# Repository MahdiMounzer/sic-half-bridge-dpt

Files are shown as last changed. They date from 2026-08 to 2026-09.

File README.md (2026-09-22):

# SiC Half-Bridge Inverter Leg + Double Pulse TEST (DPT)

A documented design-to-characterization project: a SiC half-bridge inverter leg with low-inductance 4-layer PCB, progressive bring-up, and DPT characterization (Eon/Eoff, dv/dt, overshoot, conduction losses).

## Motivation
Portfolio piece targeting EV / power electronics roles. Every design decision, measurement, and failure is documented as it happens.

## Status
**Stage0 - Design study** (operation point, device selection, gate loop, DC link, inductive load, LTspice simulation).

## Roadmap
1. Design study (Stage 0)
2. Schematic capture (KiCad)
3. 4-layer PCB - low loop inductance, kelvin source, separated power/signal
4. Progressive bring-up (20V -> 50V -> 100V -> 200V)
5. DPT characterization

## Structure
- 'design/' - design study and specifications
- 'schematic/' - KiCad schematic
- 'simulation/' - LTspice files
- 'measurements/' - DPT data, scope captures
- 'calculations/' - Math behind my choices
- 'logbook/' - chronological notes, failures learnings

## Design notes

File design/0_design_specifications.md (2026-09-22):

# Design Specifications - Stage 0

## 1. Operating point
- DC link voltage (nominal / max test): 200 V (architecture 800 V-ready)
- Target switching current: 10 A
- Switching frequency (if applicable): 50 kHz - 100 kHz
- Test type: Double Pulse Test (only the low-side device is actively switched; the high-side body diode freewheels the inductor current)

## 2. SiC MOSFET selection
Requirement: TO-247-4 with Kelvin source pin (mandatory).
Candidates:
- Wolfspeed C3M0045065K
- Infineon IMZA65R048M1H
- onsemi NTH4LN032N065M3S

Decision: **onsemi NTH4LN032N065M3S**
- Key ratings: 650 V, 32 mΩ, TO-247-4L (thin leads, Kelvin source), recommended gate drive +18 V.
- Datasheet parameters used downstream: C_iss = 1410 pF, Q_GD = 14 nC, Q_G = 55 nC, internal R_G = 5.0 Ω.
- Pinout (CASE 340CW): 1 = D, 2 = S2 (power source), 3 = S1 (Kelvin source), 4 = G.

## 3. Gate driver
Candidates:
- TI UCC21520
- TI UCC21750

Decision: **TI UCC21750** — single-channel isolated driver (±10 A, split outputs OUTH/OUTL, active Miller clamp, DESAT). One driver per switch.
- Gate resistor (Rg on / off): ~5 Ω each — provisional, **socketed** for the DPT sweep (sweep points 2.2 / 5 / 10 / 15 Ω).
- Drive voltage (+V / -V): +18 / -4
- Peak gate-current check: I_peak = V_drive / R_g,total = 22 V / 10.7 Ω ≈ 2.1 A (well under the ±10 A driver limit; internal terms already ≈ 5.7 Ω, so the current limit is never binding).

## 4. Gate loop design
- Loop area minimization strategy: minimize the commutation loop inductance — place the HF DC-link decoupling capacitor directly at the switch node, keep the gate loops short and tight, and locate the OUTH/OUTL resistors close to the gate. (Loop inductance, not the load inductance, drives turn-off overshoot.)
- Kelvin source connection: driver COM tied to the MOSFET **Kelvin-source pin (S1)**, kept separate from the power-source pin (S2) and the power-return path. This split is the sole reason for the 4-pin package.

## 5. DC link
- Capacitor type / value: **film (metallized polypropylene / MKP)**, ~100 µF bulk realized as a **parallel bank** (5 × 22 µF / 630 V, e.g. TDK B32776P6226K000), rated ≥ 500 V (2× derating of the 200 V bus).
  - Sizing: Q = ½·I·t = ½ × 10 A × 25 µs = 125 µC; C ≥ Q/ΔV = 125 µC / 2 V ≈ 63 µF → rounded to ≈ 100 µF (~1.25 V sag).
- Decoupling strategy: **two-population** — bulk film for energy storage + small HF film/ceramic at the switch node for the fast transient. Driver rails decoupled with ceramic MLCCs: 2 × 15 µF (or 22 µF) / 35 V on VDD–COM and VEE–COM, ≥ 1 µF / ≥ 25 V on VCC–GND. Voltage of each decoupling cap set by 2× derating of its *local* node; MLCC DC-bias derating accounted for (values chosen to stay > 10 µF under bias).

## 6. Inductive load
- Inductance value: **500 µH** — from L = V·Δt/ΔI = 200 V × 25 µs / 10 A (di/dt = 0.4 A/µs, ~25 µs ramp to 10 A).
- Construction / sourcing: single-winding power inductor with **I_sat ≥ 15 A**, connected **off-board via a 2-pin terminal**.
  - Primary candidate: toroid 500 µH / 15 A (Bel SAFTC-15-0501, single-winding confirmed on datasheet) — subject to stock/lead time.
  - Fallback: hand-wound single-layer **air-core coil** (cannot saturate; geometry from Wheeler's formula, value verified with an LCR meter).

## 7. Simulation
- LTspice model status: to be built next — double-pulse test from the completed schematic (two-pulse VPulse on the driver input; device model + relevant parasitics).
- Key results: TBD — E_on / E_off and V_DS overshoot vs R_g (sweep 2.2 / 5 / 10 / 15 Ω), compared against the hand-calculated switching times (~19 ns at 5 Ω).

---
**Scope note:** physical PCB fabrication deferred (cost / time). Stage 0 is validated by design calculations and LTspice simulation; the schematic, custom symbol/footprint, and full BOM are complete.

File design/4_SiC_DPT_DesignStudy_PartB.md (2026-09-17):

**SiC Half-Bridge Inverter Leg — Design Study**

Part B — Gate Drive and Supporting Subsystems

_Stage 0 (Design Study) · Double-Pulse-Test characterization board_

Selected devices: onsemi NTH4LN032N065M3S (650 V, 32 mΩ SiC MOSFET) · TI UCC21750 isolated gate driver

This document captures the engineering reasoning that follows the two headline component choices — the SiC MOSFET and the gate driver — and turns them into a complete, buildable, testable half-bridge leg. Each supporting element is derived from first principles rather than assumed. The recurring pattern throughout is deliberate: **every value is fixed by one governing physical relation and one practical limit.** That is the transferable method, not just the numbers.

# **1\. Scope and design point**

With the DUT and driver selected, five supporting subsystems remain to be defined before schematic capture: the gate-driver bias supply, the pulse source, the measurement chain, the load inductor, and the DC-link capacitors — followed by the gate resistor, which is treated in depth because its value is the primary variable the Double-Pulse Test (DPT) exists to characterize. The design operating point is summarised below.

| **Quantity** | **Value** |
| --- | --- |
| **DC bus (validation / design target)** | 200 V (800 V-ready) |
| **Test current** | 10 A |
| **Switching frequency** | 50 – 100 kHz |
| **Positive gate rail (turn-on)** | +18 V |
| **Negative gate rail (turn-off bias)**  | −4 V |
| **Gate drive swing, V_drive** | 22 V |
| **External gate resistor, R_g,ext** | 5 Ω (provisional — centre of DPT sweep) |
| **Load inductor** | 500 µH |
| **DC-link capacitance** | ≈ 100 µF film (bulk) + local HF decoupling |

# **2\. Design method**

Rather than selecting values by rule of thumb, each quantity below is bounded by a single equation and a single constraint. Recognising which relation sets a component and which limit bounds it is what makes the process repeatable on the next design without reference to worked examples.

# **3\. Gate-driver bias supply**

A gate driver's supply must be referenced to the source pin of the switch it drives. For the low-side switch, that pin sits at ground, so a ground-referenced supply is acceptable. The high-side switch's source, however, is _not_ ground: it swings to the full DC-bus potential and back on every switching event, at tens of kV/µs. Its driver supply must therefore float with it.

A single earth-referenced bench supply cannot provide a rail that rides at +200 V, and its parasitic capacitance to earth would couple the fast common-mode dV/dt into the measurement. The correct solution is a galvanically isolated bias island per driver. Because the UCC21750 is a single-channel device, two are used (one per switch), and each requires its own isolated island. A bench supply is still useful as the primary/logic-side source and as the input to the isolated DC-DC modules that generate the floating gate rails; it simply cannot be the floating rail itself.

**Design rule:** low-side driver → ground-referenced supply acceptable; high-side driver → always a galvanically isolated, floating rail (small isolated DC-DC module per driver).

# **4\. Pulse source**

The DPT is not a continuous waveform but exactly two pulses of independently set widths: a long first pulse ramps the inductor current to the target, and a short second pulse captures turn-on again at that current. A laboratory function generator (GBF) is suitable, provided it is used in burst / pulse mode (or as an arbitrary-waveform generator) and its output is conditioned to clean logic levels (0 → 3.3/5 V, offset so the input pin never sees a negative voltage). A single channel suffices, because only the device under test (the low-side switch) is actively switched; the high-side device merely freewheels through its body diode.

# **5\. Measurement chain**

Owning an oscilloscope is the trivial part; the probing determines whether the extracted energies are trustworthy. The switching energy is _E = ∫ V·I dt_, so both the voltage and current channels must be captured faithfully during nanosecond edges.

- A high-voltage differential probe for V_DS — a floating switch node cannot be measured with a ground-referenced single-ended probe.
- A fast current sensor — a low-inductance coaxial shunt or a Rogowski coil — to resolve the current edges.
- Adequate bandwidth (≈ 100–200 MHz) and, critically, deskew between the voltage and current channels: a few nanoseconds of timing mismatch corrupts the energy integral.

# **6\. Load inductor**

The inductor's role in the DPT is to act as a controllable current ramp: with the full bus voltage across it, current rises linearly. Its value is therefore chosen indirectly — a comfortable ramp time is selected first, and the inductance follows.

_di/dt = V / L → L = V · Δt / ΔI_

A ramp time of a few tens of microseconds is the sweet spot: long enough to set precisely on a function generator and resolve on a scope, short enough to avoid heating and to keep the DC-link charge demand modest. Choosing 25 µs to reach 10 A at 200 V gives:

_L = 200 V × 25 µs / 10 A = 500 µH_

![]()

_Figure 1 — Inductor current during the on-pulse. The slope is set by V/L; the shaded area is the charge the DC-link capacitors must supply._

Two constraints accompany the value. First, the inductor must not saturate at the test current — its rated saturation current needs margin above 10 A. Second, the load inductance L_load (which programs the current) must not be confused with the commutation-loop inductance L_loop (tens of nH), which is the term that drives turn-off overshoot; only L_loop appears in the overshoot equation.

# **7\. DC-link capacitors**

The DC-link capacitance performs two distinct jobs, and each sizes a different part of the two-population strategy.

## **7.1 Bulk capacitance — holding the bus during the pulse**

During the current ramp the charge is drawn from the capacitors, not from the distant HV supply (which cannot respond over microseconds through its wiring inductance). The charge delivered is the area under the ramp:

_Q = ½ · I · t = ½ × 10 A × 25 µs = 125 µC_

The bus is allowed to sag by a chosen tolerance — here ≤ 1 % of 200 V, i.e. ≈ 2 V — which sets the minimum capacitance:

_C ≥ Q / ΔV = 125 µC / 2 V ≈ 63 µF → round up to ≈ 100 µF_

At 100 µF the sag is only ≈ 1.25 V. This is a conservative worst case, since the supply does recharge slightly during the pulse — which is exactly how the project's 100–200 µF specification is derived rather than guessed.

## **7.2 Local decoupling — absorbing the fast transient**

At turn-off the current changes in nanoseconds; a large film capacitor has too much internal and loop inductance to respond that fast. Small, low-inductance capacitors (a few µF film, or ceramic) are placed directly at the switch node to handle the high-frequency transient and keep the commutation loop small — which is what governs overshoot.

## **7.3 Type and voltage rating**

- Dielectric: film (polypropylene), not electrolytic — DC-link duty demands low ESR/ESL, high ripple-current capability, and long life.
- Voltage rating: derate ≈ 2× the working bus, so 200 V → rate ≥ 400 V (select 450–500 V film). The 2× derating is applied to the working bus voltage.

# **8\. Gate resistor and switching dynamics**

## **8.1 R_ds(on) is not R_g**

A common early error is to reuse the MOSFET's 32 mΩ figure for the gate resistor. These are unrelated: R_ds(on) is the channel's conduction resistance in the high-current power path and is a fixed property of the transistor, whereas the gate resistor sits in the low-current control path between the driver output and the gate, and is a component the designer chooses. Gate resistors are measured in ohms — single digits to a few tens — never milliohms; 0.032 Ω would be effectively a short circuit.

## **8.2 Peak gate current: equation and limit**

The gate resistor is bounded by a single relation and a single constraint:

_I_peak = V_drive / R_g,total (limit: I_peak ≤ ±10 A, the UCC21750 rating)_

The drive swing is V_drive = +18 − (−4) = **22 V**. The total resistance in the gate loop is the sum of three series terms, only one of which is chosen by the designer:

_R_g,total = R_driver + R_g,ext + R_g,int_

As a sanity check, the (incorrect) 32 mΩ value would demand I_peak ≈ 22 V / 0.032 Ω ≈ 600 A — roughly 60× the driver's ceiling. Substituting a value and checking it against the limit is the habit worth building.

## **8.3 The floor — and why the limit is not binding**

The minimum permissible total resistance is:

_R_g,total(min) = 22 V / 10 A = 2.2 Ω_

But the driver's internal pull-up (≈ 0.7 Ω) and the MOSFET's internal gate resistance (5.0 Ω) already sum to ≈ 5.7 Ω — above the 2.2 Ω floor. Even with R_g,ext = 0, peak current is only ≈ 22 / 5.7 ≈ 4 A. The current limit is therefore **never the binding constraint**. External R_g stops being a limit-driven choice and becomes purely the switching-speed-versus-overshoot knob. (The UCC21750's split outputs, OUTH and OUTL, further allow independent turn-on and turn-off resistors.)

## **8.4 The Miller plateau — what actually sets switching speed**

The switching event does not occur while the gate is charging up; it occurs during the flat region of the gate-charge curve — the Miller plateau. The gate charges in four acts:

- Delay — the gate climbs from −4 V toward threshold; the switch is still off and nothing happens at the drain.
- Current rise — past threshold, the drain current ramps 0 → 10 A while V_DS is still high.
- Miller plateau — V_GS holds flat while the drain voltage swings 200 V → 0. All gate current here moves the Miller charge Q_GD. This region produces most of E_on.
- Full enhancement — V_GS resumes rising to +18 V to minimise R_ds(on); no further switching loss.

![]()

_Figure 2 — Gate-source voltage vs gate charge (from the onsemi data). Switching happens in the shaded plateau, where V_DS swings and the driver moves Q_GD._

V_GS freezes during the plateau because the collapsing V_DS drives a displacement current through the gate–drain capacitance (C_gd · dV_DS/dt) that absorbs essentially all of the driver's gate current, leaving none to raise V_GS until Q_GD has been ferried across. During the plateau the gate sits at the plateau voltage (≈ 10 V, read from the gate-charge curve) while the driver rail is at +18 V, so the available current — and the resulting plateau duration — are:

_I_g,plateau = (18 − 10) / R_g,total = 8 / 10.7 ≈ 0.75 A_

_t_plateau = Q_GD / I_g,plateau = 14 nC / 0.75 A ≈ 19 ns_

This ≈ 19 ns is the real V_DS transition time — the honest counterpart of a naïve RC estimate. Note it is smaller than the ≈ 2.1 A peak gate current, which occurs back at the start of turn-on when the full 22 V is across R_g. (At the 200 V bus, Q_GD is somewhat below its 400 V datasheet value, so the true transition is a little faster.)

## **8.5 R_g as the design lever**

Rearranging shows the switching time is directly proportional to gate resistance:

_t_plateau = Q_GD · R_g,total / (V_rail − V_plateau) ∝ R_g,total_

Q_GD, V_rail and V_plateau are fixed by the device and the rails; only R_g,total moves. Because the turn-on energy scales as

_E_on ≈ ½ · V_bus · I_load · t_transition_

doubling the plateau time roughly doubles the turn-on loss. The trade-off is monotonic — larger R_g means slower switching, lower loss headroom is spent, and overshoot is tamed; smaller R_g means the reverse:

| **R_g,ext** | **R_g,total** | **t_plateau (approx.)** |
| --- | --- | --- |
| **2.2 Ω** | ≈ 7.9 Ω | ≈ 14 ns (faster · less loss · more overshoot)  |
| **5 Ω** | ≈ 10.7 Ω | ≈ 19 ns (baseline / centre) |
| **15 Ω** | ≈ 20.7 Ω | ≈ 37 ns (slower · more loss · tamer overshoot) |

## **8.6 Selection status**

R_g,ext is left at a provisional 5 Ω (centre of the intended sweep) on a swappable footprint. The formula predicts the trend; the exact E_on/E_off and overshoot at each value are obtained by **measurement on the DPT bench**, not by simulation — at these edge speeds the outcome is dominated by real parasitics (loop inductance, layout, Kelvin connection) that simulation models imperfectly. LTspice may preview the trend and help bound the range, but the measured E_on/E_off-versus-R_g curve is the definitive result and the portfolio deliverable.

# **9\. Selected-device parameters**

Key figures used in the calculations above, for reference during schematic capture.

| **Parameter** | **Symbol**  | **Value** | **Source** |
| --- | --- | --- | --- |
| **On-resistance** | R_ds(on) | 32 mΩ | onsemi datasheet |
| **Input capacitance** | C_iss | 1410 pF | onsemi datasheet |
| **Output capacitance** | C_oss | 114 pF | onsemi datasheet |
| **Reverse-transfer cap.** | C_rss | 9.2 pF | onsemi datasheet |
| **Total gate charge** | Q_G(tot) | 55 nC | onsemi (V_GS = −3/18 V)  |
| **Gate–source charge** | Q_GS | 15 nC | onsemi datasheet |
| **Gate–drain (Miller) charge**  | Q_GD | 14 nC | onsemi (at V_DS = 400 V) |
| **Internal gate resistance** | R_G | 5.0 Ω | onsemi datasheet |
| **Driver peak source / sink** | I_OH / I_OL | ±10 A | UCC21750 datasheet |
| **Driver internal pull-up** | R_OH_EFF | ≈ 0.7 Ω | UCC21750 datasheet |
| **Driver internal pull-down** | R_OL | ≈ 0.3 Ω | UCC21750 datasheet |
| **Driver common-mode immunity** | CMTI | \> 150 V/ns | UCC21750 datasheet |

# **10\. Open items and next step**

- Select a specific isolated bias module (one per driver) delivering the +18 / −4 V rails.
- Assign DC-link part numbers: a ≈ 100 µF, ≥ 500 V film bulk bank plus local HF decoupling at the switch node.
- Decide the current-sense method (coaxial shunt vs Rogowski) — it changes the PCB, so it must be fixed before layout.
- Define the R_g sweep as a formal experiment (fixed conditions, swept values, captured quantities), then proceed to Stage 1 (KiCad schematic).

_Working design document — values provisional pending DPT measurement._

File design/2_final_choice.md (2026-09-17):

**MOSFET Selection Study — Final Comparison**

**Three-way SiC candidate comparison & device selection**

SiC Half-Bridge Inverter Leg · DPT Characterization — Stage 0 Design Study

## **Scope & method**

Three discrete 650 V SiC MOSFETs in TO-247-4 (Kelvin source) packages are compared for the half-bridge inverter leg. Each was analysed in its own device document (reading → derivation → loss summary). This document consolidates the results and makes the selection.

All three are evaluated under identical assumptions so the comparison isolates the device: 200 V bus, I_peak = 10 A, hard-switched duty D = 0.5 (I_rms = 7.07 A), junction temperature 175 °C (worst case), switching loss reported at 50 and 100 kHz. Conduction loss uses R_ds(on) at 175 °C; switching loss uses datasheet E_on/E_off rescaled to 200 V / 10 A (E ∝ V·I), all at 175 °C.

# **1 · Candidates**

| **Manufacturer** | **Part number**  | **Technology** | **R_ds(on) 25°C** | **Package** |
| --- | --- | --- | --- | --- |
| Infineon | IMZA65R048M1H | CoolSiC M1 | 48 mΩ | TO-247-4 ✓  |
| Wolfspeed | C3M0045065K | C3M (Gen3) | 45 mΩ | TO-247-4 ✓  |
| onsemi | NTH4LN032N065M3S | EliteSiC M3S | 32 mΩ | TO-247-4L ✓ |

_All three pass the hard filters: genuine silicon carbide, 650 V class, TO-247-4 with a Kelvin (driver-source) pin, and V_GS windows compatible with the TI UCC21520 driver. The onsemi part is specified at an 18 V gate drive (the others at 15 V); the UCC21520 supports both._

# **2 · Loss comparison**

_All values at 200 V / 10 A / D = 0.5 / 175 °C. Lowest value in each row is the best performer._

## **2.1 · Conduction loss (frequency-independent)**

| **Quantity** | **Infineon** | **Wolfspeed** | **onsemi** | **Unit** |
| --- | --- | --- | --- | --- |
| R_ds(on) @175 °C | 67 | 61 | 49 | mΩ |
| I_rms (D = 0.5)  | 7.07 | 7.07 | 7.07 | A |
| **P_cond** | 3.35 | 3.05 | **2.45** | W |

## **2.2 · Switching loss (per device)**

| **Quantity** | **Infineon** | **Wolfspeed** | **onsemi** | **Unit** |
| --- | --- | --- | --- | --- |
| E_on + E_off (200 V/10 A) | 25.6 | 20.2 | 18.6 | µJ |
| **P_sw @ 50 kHz** | 1.28 | 1.01 | **0.93** | W |
| **P_sw @ 100 kHz** | 2.56 | 2.02 | **1.86** | W |

## **2.3 · Total loss — P_tot = P_cond + P_sw**

| **P_tot** | **Infineon** | **Wolfspeed** | **onsemi** | **Unit** |
| --- | --- | --- | --- | --- |
| **@ 50 kHz**  | 4.63 | 4.06 | **3.38** | W |
| **@ 100 kHz** | 5.91 | 5.07 | **4.31** | W |

**Ranking on total loss (both frequencies):** onsemi < Wolfspeed < Infineon. The onsemi 32 mΩ die wins on both loss families — its lower R_ds(on) drives conduction down, and it also carries the lowest switching loss even after the 175 °C correction.

# **3 · Frequency dependence**

The two loss families behave oppositely with frequency: P_cond is constant, while P_sw rises linearly with f_sw. This shifts which family dominates and therefore what the comparison rewards.

- At 50 kHz, conduction dominates every candidate (e.g. onsemi 2.45 W conduction vs 0.93 W switching) — the ranking is driven mainly by R_ds(on).
- At 100 kHz, switching loss roughly doubles and closes part of the gap, but does not change the order here — onsemi's conduction advantage is large enough to hold the lead.

_Because the design targets the 50–100 kHz range, the 100 kHz worst case is used for thermal sizing. The ranking is stable across the range, so the selection does not depend on the exact operating frequency._

# **4 · Secondary axes (tie-breaks & robustness)**

| **Axis** | **Infineon** | **Wolfspeed** | **onsemi** | **Reads as** |
| --- | --- | --- | --- | --- |
| Body diode V_F | 4.0 V | 4.8 V | 4.5 V | Dead-time conduction; Infineon best  |
| Q_rr | 125 nC\* | 171 nC | 72 nC | Recovery loss/ringing; onsemi best |
| C_oss (max) | 168 pF | 101 pF | 114 pF | Overshoot/ringing; Wolfspeed best |
| Q_g | 33 nC | 63 nC | 55 nC | Driver load; Infineon lightest |
| Gate drive | 15 V | 15 V | 18 V | onsemi needs 18 V for rated R_ds(on) |

_\* Infineon lists Q_fr (forward recovery, includes Q_oss); classical Q_rr is near-zero for all three SiC parts. All Q_rr/Q_fr values are small — the SiC advantage over silicon (where this figure would be thousands of nC) holds across the board._

No secondary axis overturns the loss ranking. onsemi has the lowest Q_rr; Wolfspeed the lowest C_oss; Infineon the lightest gate charge and lowest V_F. These are second-order next to the ~1.6 W P_tot spread at 100 kHz.

# **5 · Selection & rationale**

**Primary pick: onsemi NTH4LN032N065M3S.**

It gives the lowest total loss at both frequencies (4.31 W vs 5.07 / 5.91 W at 100 kHz), the lowest reverse-recovery charge, and low output capacitance. The margin comes chiefly from its 32 mΩ die, which suppresses the conduction loss that dominates at these frequencies.

**Honest qualifications (the engineering reading behind the raw numbers):**

- Lower-resistance die. The onsemi part is 32 mΩ vs 45–48 mΩ for the others — not a perfectly like-for-like die, so some of its advantage is that it is simply a larger/lower-R device. Fair for a best-performer choice, but worth stating.
- 18 V gate drive required. Its rated R_ds(on) assumes an 18 V drive. The UCC21520 supports this, but the gate supply must be designed for +18 V (and a negative off-rail), not the +15 V the other two use.
- Temperature-corrected switching. Its switching loss was recomputed at 175 °C (E_off nearly doubles vs 25 °C). Without that correction the comparison would have flattered onsemi further; the ranking holds even after it.

**Cleanest like-for-like: Infineon vs Wolfspeed.**

These two are near-identical dies (48 vs 45 mΩ), both 15 V drive, both effectively hot data — the most directly comparable pair. Wolfspeed wins that head-to-head on every loss axis (P_tot 5.07 vs 5.91 W at 100 kHz), making it the natural second choice and a strong fallback if a 15 V-only gate scheme is preferred.

## **Estimate status & next step**

These P_tot figures are first-order estimates: switching energy from datasheet E_on/E_off rescaled linearly, and a simplified D = 0.5 hard-switched conduction condition. They are sufficient to rank the three candidates, and the ranking is robust across the 50–100 kHz range. The selected device proceeds to: (1) the Double Pulse Test, which replaces the estimated E_on/E_off with measured values at the true operating point, and (2) a realistic sinusoidal-inverter thermal-validation model using that measured data to confirm T_j stays within the 175 °C limit on the chosen heatsink.

**Decision**

**Select onsemi NTH4LN032N065M3S (lowest P_tot, 18 V drive).** Fallback: Wolfspeed C3M0045065K (best 15 V-drive option, cleanest peer to the Infineon baseline). Confirm with DPT-measured switching energies before committing to fabrication.

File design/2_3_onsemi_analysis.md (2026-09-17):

MOSFET Selection Study — Device Analysis

onsemi NTH4LN032N065M3S

_EliteSiC™ M3S — 650 V SiC MOSFET · TO-247-4L (Kelvin source)_

SiC Half-Bridge Inverter Leg · DPT Characterization — Stage 0 Design Study

## **Application operating point (cahier des charges)**

| **Parameter** | **Value** |
| --- | --- |
| DC bus voltage (V_DS test) | 200 V |
| Test current (I_D) | 10 A |
| Switching frequency | 50 – 100 kHz |
| Gate driver | TI UCC21520 |
| Design junction temp (T_j) | 175 °C (worst case) |

# **1 · Datasheet parameters (reading only)**

_Values read directly from the NTH4LN032N065M3S datasheet (Rev 2), source noted. No calculation at this stage._

| **Parameter** | **Symbol** | **Value** | **Unit** | **Source** |
| --- | --- | --- | --- | --- |
| **Package / Kelvin source** | — | **TO-247-4L ✓** | — | p.1 |
| Drain-source voltage | V_DS | 650 | V | Max Ratings |
| Gate-source range (op.) | V_GS | −5…0 / +18 | V | Rec. Op. |
| Gate threshold | V_GS(th) | 2.0 / 2.7 / 4.0 | V | Elec. |
| **R_ds(on) @ 25 °C** | R_DS(on) | **32** | mΩ | Elec. (VGS=18V) |
| **R_ds(on) @ 175 °C** | R_DS(on) | **49** | mΩ | Elec. (VGS=18V) |
| Internal gate resistance | R_G | 5.0 | Ω | Elec. |
| Output capacitance | C_oss | 114 | pF | Elec. |
| Total gate charge | Q_g | 55 | nC | Elec. |
| **Turn-on energy (given)**  | E_on | **31** | µJ | Elec. (175 °C)  |
| **Turn-off energy (given)** | E_off | **25** | µJ | Elec. (175 °C)  |
| E-test conditions | — | 400 V, 15 A, 175 °C, R_g=4.7 Ω | — | Elec. |
| Rise / fall time | t_r / t_f  | 12 / 9 | ns | Elec. |
| **Body-diode fwd drop** | V_SD | **4.5** | V | Diode (25 °C) |
| **Reverse recovery charge** | Q_rr | 72 | nC | Diode |

_Notes — E_on/E_off are given directly. The M3S is a planar SiC device recommended for 18 V gate drive (works at 15 V); R_ds(on) here is specified at V_GS = 18 V, so the drive scheme must match to realise this resistance. This study uses onsemi's 175 °C E-values (E_on 31 µJ, E_off 25 µJ), matching the hot condition of the Wolfspeed data and the final comparison; the 25 °C typical set (E_on 33 µJ, E_off 16 µJ) is noted for reference only._

# **2 · Reasoning & calculations**

Two loss families are computed at the application point (200 V / 10 A / f_sw): conduction and switching.

## **2.1 · Conduction loss**

Conduction loss uses the RMS current and the hot resistance. For a hard-switched pulse, I_rms = I_peak·√D with D = 0.5 applied identically across candidates.

_I_rms = 10 · √0.5 = 7.07 A_

_P_cond = R_ds(on)@175°C × I_rms² = 0.049 × (7.07)² = 0.049 × 50 = 2.45 W_

_This is the lowest conduction loss of the three candidates — a direct consequence of the 32 mΩ die (vs 45–48 mΩ). Note it assumes the 18 V drive that the R_ds(on) spec requires._

## **2.2 · Switching loss**

E_on and E_off are given directly. Rescale from the datasheet test point to the application point; E ∝ V·I.

**Datasheet test point: 400 V, 15 A. Application point: 200 V, 10 A.**

_k = (200/400) × (10/15) = 0.5 × 0.667 = 0.333_

_E_on = 31 × 0.333 = 10.3 µJ E_off = 25 × 0.333 = 8.3 µJ_

_E_on + E_off ≈ 18.6 µJ per cycle_

_P_sw = (E_on + E_off) × f_sw_

_Caveat: E-values are now onsemi's 175 °C set, so the switching estimate sits on the same hot footing as the Wolfspeed data and the final comparison. The 25 °C typical figures (E_on + E_off ≈ 16.3 µJ → P_sw 1.63 W at 100 kHz) understate loss by ~13 % and are kept only as a reference floor. Both remain first-order until replaced by measured DPT energies._

## **2.3 · Which frequency**

P_cond is frequency-independent; P_sw grows linearly with f_sw. Report both; design against the 100 kHz worst case.

# **3 · Loss summary (values to compare)**

_Operating assumptions: 200 V, I_peak = 10 A, D = 0.5 (I_rms = 7.07 A), R_ds(on)@175 °C = 49 mΩ. E-values are onsemi's 175 °C set._

| **Quantity** | **@ 50 kHz** | **@ 100 kHz** | **Unit** |
| --- | --- | --- | --- |
| E_on (rescaled, 200 V/10 A)  | 10.3 | 10.3 | µJ |
| E_off (rescaled, 200 V/10 A) | 8.3 | 8.3 | µJ |
| E_on + E_off | 18.6 | 18.6 | µJ |
| I_rms (D = 0.5) | 7.07 | 7.07 | A |
| **P_sw (switching loss)** | **0.93** | **1.86** | W |
| **P_cond (conduction loss)** | **2.45** | **2.45** | W |
| **P_tot = P_cond + P_sw** | **3.38** | **4.31** | W |

**Secondary comparison axes (for tie-breaks):**

| **Axis** | **Value** | **Comment** |
| --- | --- | --- |
| Body diode V_F | 4.5 V | Dead-time conduction loss |
| Q_rr | 72 nC | Lowest recovery charge of the three |
| C_oss | 114 pF | Low |
| Q_g | 55 nC | Moderate; needs 18 V drive for rated R_ds(on) |

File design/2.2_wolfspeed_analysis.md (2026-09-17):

**MOSFET Selection Study — Device Analysis**

**Wolfspeed C3M0045065K**

_C3M™ — 650 V SiC MOSFET · TO-247-4 (Kelvin source)_

SiC Half-Bridge Inverter Leg · DPT Characterization — Stage 0 Design Study

## **Application operating point (cahier des charges)**

| **Parameter** | **Value** |
| --- | --- |
| DC bus voltage (V_DS test) | 200 V |
| Test current (I_D) | 10 A |
| Switching frequency | 50 – 100 kHz |
| Gate driver | TI UCC21520 |
| Design junction temp (T_j) | 175 °C (worst case) |

# **1 · Datasheet parameters (reading only)**

_Values read directly from the C3M0045065K datasheet (Rev 04), source noted. No calculation at this stage._

| **Parameter** | **Symbol** | **Value** | **Unit** | **Source** |
| --- | --- | --- | --- | --- |
| **Package / Kelvin source** | — | **TO-247-4 ✓** | — | p.1 |
| Drain-source voltage | V_DS | 650 | V | Key Param |
| Gate-source range (op.) | V_GS | −4 / +15 | V | Key Param |
| Gate threshold | V_GS(th) | 1.8 / 2.6 / 3.6 | V | Elec. |
| **R_ds(on) @ 25 °C** | R_DS(on) | **45** | mΩ | Elec. (VGS=15V) |
| **R_ds(on) @ 175 °C** | R_DS(on) | **61** | mΩ | Elec. (VGS=15V) |
| Internal gate resistance | R_G,int | 3 | Ω | Elec. |
| Output capacitance | C_oss | 101 | pF | Elec. |
| Total gate charge | Q_g | 63 | nC | Elec. |
| **Turn-on energy (given)**  | E_on | **57** | µJ | Elec. (body diode) |
| **Turn-off energy (given)** | E_off | **14** | µJ | Elec. (body diode) |
| E-test conditions | — | 400 V, 17.6 A, 175 °C, R_g=2.5 Ω | — | Elec. |
| Rise / fall time | t_r / t_f  | 12 / 6 | ns | Elec. |
| **Body-diode fwd drop** | V_F | **4.8** | V | Diode (25 °C) |
| **Reverse recovery charge** | Q_rr | 171 | nC | Diode |

_Note — E_on/E_off are provided directly by Wolfspeed (unlike the Infineon part, which had to be derived). They are measured with the internal body diode as the freewheeling device, at 175 °C — already the hot condition, so no temperature correction is needed._

# **2 · Reasoning & calculations**

Two loss families are computed at the application point (200 V / 10 A / f_sw): conduction and switching.

## **2.1 · Conduction loss**

Conduction loss is driven by the RMS current, using the hot resistance. For a hard-switched pulse of amplitude I_peak present a fraction D of each period, I_rms = I_peak·√D. Consistent with the study, D = 0.5 is applied identically to all candidates so the comparison isolates R_ds(on).

_I_rms = 10 · √0.5 = 7.07 A_

_P_cond = R_ds(on)@175°C × I_rms² = 0.061 × (7.07)² = 0.061 × 50 = 3.05 W_

## **2.2 · Switching loss**

E_on and E_off are given directly, so no derivation from t_r/t_f is required — only a rescale from the datasheet test point to the application point. Switching energy scales linearly with voltage and current (E ∝ V·I).

**Datasheet test point: 400 V, 17.6 A. Application point: 200 V, 10 A.**

_k = (200/400) × (10/17.6) = 0.5 × 0.568 = 0.284_

_E_on = 57 × 0.284 = 16.2 µJ E_off = 14 × 0.284 = 3.98 µJ_

_E_on + E_off ≈ 20.2 µJ per cycle_

_P_sw = (E_on + E_off) × f_sw_

_Caveat: the current-rescale assumes switching energy is proportional to current at fixed R_g; the datasheet value already sits at 175 °C, the design worst case._

## **2.3 · Which frequency**

P_cond is frequency-independent; P_sw grows linearly with f_sw. Both extremes are reported; design against the 100 kHz worst case.

# **3 · Loss summary (values to compare)**

_Operating assumptions: 200 V, I_peak = 10 A, D = 0.5 (I_rms = 7.07 A), R_ds(on)@175 °C = 61 mΩ._

| **Quantity** | **@ 50 kHz** | **@ 100 kHz** | **Unit** |
| --- | --- | --- | --- |
| E_on (rescaled, 200 V/10 A)  | 16.2 | 16.2 | µJ |
| E_off (rescaled, 200 V/10 A) | 3.98 | 3.98 | µJ |
| E_on + E_off | 20.2 | 20.2 | µJ |
| I_rms (D = 0.5) | 7.07 | 7.07 | A |
| **P_sw (switching loss)** | **1.01** | **2.02** | W |
| **P_cond (conduction loss)** | **3.05** | **3.05** | W |
| **P_tot = P_cond + P_sw** | **4.06** | **5.07** | W |

**Secondary comparison axes (for tie-breaks):**

| **Axis** | **Value** | **Comment** |
| --- | --- | --- |
| Body diode V_F | 4.8 V | Dead-time conduction loss |
| Q_rr | 171 nC | Low SiC recovery |
| C_oss | 101 pF | Lower than Infineon → less ringing |
| Q_g | 63 nC | Higher gate charge; UCC21520 still drives it |

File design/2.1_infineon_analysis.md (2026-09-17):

**MOSFET Selection Study — Device Analysis**

**Infineon IMZA65R048M1H**

_CoolSiC™ M1 — 650 V SiC MOSFET · PG-TO247-4 (Kelvin source)_

SiC Half-Bridge Inverter Leg · DPT Characterization — Stage 0 Design Study

## **Application operating point (cahier des charges)**

| **Parameter** | **Value** |
| --- | --- |
| DC bus voltage (V_DS test) | 200 V |
| Test current (I_D) | 10 A |
| Switching frequency | 50 – 100 kHz |
| Gate driver | TI UCC21520 |
| Design junction temp (T_j) | 175 °C (worst case) |

# **1 · Datasheet parameters (reading only)**

_Values read directly from the IMZA65R048M1H datasheet (Rev 2.2), with the table/diagram source noted. No calculation at this stage — this is the raw ingredient list._

| **Parameter** | **Symbol** | **Value** | **Unit** | **Source** |
| --- | --- | --- | --- | --- |
| **Package / Kelvin source** | — | **TO-247-4 ✓** | — | p.1 |
| Drain-source voltage | V_DS | 650 | V | Table 1 |
| V_DS breakdown @175 °C | V_DSS | ≈ 685 | V | Diagram 14 |
| Gate-source range (op.) | V_GS | −2 / +20 | V | Table 4 |
| Recommended drive | V_GS(on/off) | +18 / 0 | V | Table 4 |
| Gate threshold | V_GS(th) | 3.5 / 4.5 / 5.7 | V | Table 5 |
| **R_ds(on) @ 25 °C** | R_DS(on) | **48** | mΩ | Table 5 |
| **R_ds(on) @ 175 °C** | R_DS(on) | **67** | mΩ | Table 5 |
| Internal gate resistance | R_G,int | 6.0 | Ω | Table 5 |
| Output capacitance | C_oss | 129 / 168 (max) | pF | Table 6 |
| Output charge | Q_oss | 78 | nC | Table 1 |
| Total gate charge | Q_g | 33 | nC | Table 7 |
| Turn-on delay | t_d(on) | 14.8 | ns | Table 6 |
| **Rise time** | t_r | **12.6** | ns | Table 6 |
| Turn-off delay | t_d(off) | 17 | ns | Table 6 |
| **Fall time** | t_f | **13** | ns | Table 6 |
| **Body-diode fwd drop (V_F)** | V_SD | **4.0** | V | Table 8 |
| **Fwd recovery charge** | Q_fr | **125** | nC | Table 8 |
| Switching-loss test cond. | — | 400 V, 20.1 A, R_g=1.8 Ω | — | Table 6 |

**Notes on the 'missing' parameters:** E_on/E_off are not tabulated — they are derived from t_r/t_f (Section 2). Q_rr does not exist for a SiC body diode (near-zero reverse recovery — SiC's key advantage); the datasheet gives Q_fr instead. V_F is listed as V_SD (source-drain voltage).

# **2 · Reasoning & calculations**

The datasheet gives raw ingredients at its own test conditions. The engineering step is to convert these into application-specific loss figures at 200 V / 10 A / f_sw. Two loss families are computed: conduction and switching.

## **2.1 · Conduction loss**

A conducting MOSFET behaves as a resistor R_ds(on). Loss is I²R, using the HOT resistance (175 °C), never the 25 °C value — SiC R_ds(on) rises ≈1.4× with temperature.

_P_cond = R_ds(on)@175°C × I_rms²_

**Step 1 — why I_rms, not the 10 A peak.** What heats a resistor is the mean of the square of the current, so conduction loss is driven by the RMS current, not the peak. The 10 A is the peak drain current while the device is fully on — but the MOSFET conducts only for a fraction D of each switching period (its duty cycle) and carries zero the rest of the time.

**Step 2 — I_rms for a hard-switched (rectangular) current.** Modelling the drain current as a pulse of amplitude I_peak present for D·T and zero for (1−D)·T, the RMS definition gives:

_I_rms = √\[ (1/T) ∫ i² dt \] = √( I_peak² · D ) = I_peak · √D_

The period T cancels — I_rms depends on the fraction of time conducting, not the frequency.

**Step 3 — operating assumption: D = 0.5.** A duty cycle of 0.5 is chosen for the device-selection stage. It is the natural operating point of a symmetric half-bridge and, crucially, it is applied identically to all three candidates — so the conduction-loss comparison isolates the effect of R_ds(on) (the parameter under evaluation) rather than the operating scenario.

_I_rms = 10 · √0.5 = 7.07 A_

**Step 4 — conduction loss.**

_P_cond = 0.067 × (7.07)² = 0.067 × 50 = 3.35 W_

**Scope note (to state in the report):** _D = 0.5 is a deliberately simplified condition for ranking. A realistic sinusoidal-current inverter model (variable duty over the fundamental cycle, worst-case operating point) will be applied to the_ **_selected_** _device in the thermal-validation stage, using the measured E_on/E_off from the DPT rather than datasheet estimates._

## **2.2 · Switching loss — deriving E_on / E_off**

During a transition, V and I overlap → energy is dissipated. First-order (triangular) estimate:

_E_on ≈ ½ · V_DS · I_D · t_r E_off ≈ ½ · V_DS · I_D · t_f_

**Step 1 — base energies at datasheet conditions (400 V, 20.1 A):**

_E_on ≈ ½ (400)(20.1)(12.6 ns) = 50.7 µJ_

_E_off ≈ ½ (400)(20.1)(13 ns) = 52.3 µJ_

**Step 2 — rescale to the application point.** Switching energy scales linearly with both voltage and current (E ∝ V·I), because it is a V·I·t area. Transition times are held constant (same R_g family) — a first-order assumption.

_k = (V_your/V_ds) × (I_your/I_ds) = (200/400) × (10/20.1) = 0.5 × 0.498 = 0.249_

**Step 3 — energies at 200 V / 10 A:**

_E_on ≈ 50.7 × 0.249 = 12.6 µJ E_off ≈ 52.3 × 0.249 = 13.0 µJ_

_E_on + E_off ≈ 25.6 µJ per cycle_

**Step 4 — convert to power at the switching frequency:**

_P_sw = (E_on + E_off) × f_sw_

**Honest caveats (to state in the report):**

- t_r/t_f are voltage rise/fall times, not the exact V–I overlap window → the ½VIt figure is an estimate, adequate for comparing candidates.
- Transition times assumed constant across the rescale; in reality they vary with current and R_g.
- The DPT exists precisely to replace these estimates with measured E_on/E_off.

## **2.3 · Which frequency**

P_cond is frequency-independent; P_sw grows linearly with f_sw. Report both extremes and design against the 100 kHz worst case (highest switching loss → safest thermal margin).

# **3 · Loss summary (values to compare)**

_Final computed quantities for cross-candidate comparison. P_tot is the primary ranking metric._

_Operating assumptions: 200 V bus, I_peak = 10 A, D = 0.5 (→ I_rms = 7.07 A), R_ds(on)@175 °C = 67 mΩ._

| **Quantity** | **@ 50 kHz** | **@ 100 kHz** | **Unit** |
| --- | --- | --- | --- |
| E_on (200 V / 10 A) | 12.6 | 12.6 | µJ |
| E_off (200 V / 10 A) | 13.0 | 13.0 | µJ |
| E_on + E_off | 25.6 | 25.6 | µJ |
| I_rms (D = 0.5) | 7.07 | 7.07 | A |
| **P_sw (switching loss)** | **1.28** | **2.56** | W |
| **P_cond (conduction loss)** | **3.35** | **3.35** | W |
| **P_tot = P_cond + P_sw** | **4.63** | **5.91** | W |

**Secondary comparison axes (for tie-breaks):**

| **Axis** | **Value** | **Comment** |
| --- | --- | --- |
| Body diode V_F | 4.0 V | Dead-time conduction loss; high, typical of SiC |
| Q_fr (≈ Q_rr)  | 125 nC | Near-zero classical recovery — SiC advantage |
| C_oss (max) | 168 pF | Overshoot / ringing driver |
| Q_g | 33 nC | Driver load; low → fast, UCC21520-compatible |

_Next: repeat this document for the onsemi (NTH4L040N065M3S) and Wolfspeed (C3M0065090J) candidates under the same assumptions, then compare P_tot at 100 kHz to rank the three. The selected device then proceeds to realistic sinusoidal-inverter thermal validation using measured DPT data._

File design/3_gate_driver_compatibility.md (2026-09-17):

# Gate driver compatibility — UCC21520 & UCC21750 vs onsemi NTH4LN032N065M3S

*SiC half-bridge inverter leg — DPT characterization · Stage 0 (design study)*

Both candidate gate drivers are checked against the selected switch
(onsemi NTH4LN032N065M3S, 650 V / 32 mΩ SiC, TO-247-4L). Compatibility is
evaluated on seven axes: can the driver deliver the required gate swing, fast
enough, without exceeding any limit, and survive the electrical environment the
SiC creates.

## UCC21520 / onsemi NTH4LN032N065M3S

| Axis | What I compare | UCC21520 | onsemi MOSFET | Verdict |
|---|---|---|---|---|
| **Gate voltage rails** — can it deliver +18/−4 without exceeding V_GS max? | Driver VDD−VSS rail vs MOSFET recommended & abs-max V_GS | VDD−VSS < 25 V rec (30 V abs) | Rec. −5…0/+18 V; abs max −10/+22.6 V static | ✅ +18/−4 → 22 V rail (< 25 V), gate well inside −10/+22.6 |
| **UVLO matches the drive scheme** (the SiC-critical one) | Driver UVLO vs VGS below which R_DS(on) balloons | 8 V version: 8.5 V rise / 7.9 V fall | 32 mΩ@18 V but **41 mΩ@15 V** — very VGS-sensitive | ⚠️ Use the **8 V UVLO part (UCC21520), not the 5 V "A" variant** — see note |
| **Peak current / drive strength** | Peak I_G = ΔV_GS / R_g,total vs driver peak | 4 A source / 6 A sink; R_OH = 5 Ω, R_OL = 0.55 Ω | R_g,int = 5 Ω | ✅ Even at R_ext = 0: turn-on ≈ 22/10 = 2.2 A, turn-off ≈ 22/5.5 ≈ 4 A — under limits; driver never the bottleneck |
| **Average drive power** | P = Q_g·ΔV_GS·f_sw vs driver P_D and bias-supply current | 450 mW/side; ~950 mW total | Q_g = 55 nC | ✅ 55n·22·100k ≈ **0.12 W/switch**; I_avg ≈ 5.5 mA/ch — trivial |
| **CMTI vs dV/dt** | Switching-node dV/dt vs driver CMTI | **> 125 V/ns** | ~10–30 V/ns expected at 200 V bus | ✅ Comfortable, provided R_g keeps dV/dt under 125 V/ns |
| **Timing: dead-time, prop delay, min pulse** | DPT / dead-time plan vs driver timing | Prog. DT = 10·R_DT(kΩ); t_pd 33 ns; PWD 6 ns; t_pw,min 20 ns | Dead-time target 100–200 ns | ✅ 150 ns → R_DT = 15 kΩ; delays negligible vs µs DPT pulses |
| **False turn-on protection** | MOSFET V_GS(th) & Miller vs driver clamp features | **No integrated Miller clamp** | V_GS(th) = **2.0 V min** (low!) | ⚠️ Compatible **only with negative off-bias** — see note |

### The two judgement calls

- **UVLO subtlety (row 2).** SiC R_DS(on) collapses only near full drive, so the
  device must never operate far below 18 V. The UCC21520's UVLO watches
  VDD−**VSS**, so with a −4 V floor the 8.5 V trip really means the positive rail
  can sag to ~4.5 V before lockout — not ideal in theory. In practice, with a
  well-regulated isolated bias supply both rails move together and it is a
  non-issue for a ≤200 V bench DPT. Honest note: a production traction inverter
  would often use a driver with a dedicated ~13 V SiC UVLO (e.g. the UCC21750,
  evaluated below).
- **Miller clamp (row 7).** The UCC21520 has no active Miller clamp, so with this
  onsemi part's low 2.0 V threshold the only defence against dV/dt-induced false
  turn-on is the −4 V negative bias plus a tight, low-inductance gate loop.
  Workable, but it leaves no on-chip safety net — the main reason to also look at
  a driver that has one (below).

## UCC21750 / onsemi NTH4LN032N065M3S

Same compatibility check, now against the traction-grade UCC21750. It is a
single-channel isolated SiC/IGBT driver, so a half-bridge leg needs two of
them — but it adds protection and sensing the UCC21520 does not have.

| Axis | What I compare | UCC21750 | onsemi MOSFET | Verdict |
|---|---|---|---|---|
| **Gate voltage rails** — can it deliver +18/−4 without exceeding V_GS max? | Driver VDD−VEE rail vs MOSFET recommended & abs-max V_GS | VDD−VEE ≤ **33 V** rec (36 V abs); split output (VDD + VEE rails) | Rec. −5…0/+18 V; abs max −10/+22.6 V static | ✅ +18/−4 → 22 V rail (well under 33 V), large headroom; gate well inside −10/+22.6 |
| **UVLO matches the drive scheme** (the SiC-critical one) | Driver UVLO vs VGS below which R_DS(on) balloons | **12 V** VDD UVLO (12.0 V rise / 10.7 V fall), referenced to VDD−**COM** (the source) | 32 mΩ@18 V but **41 mΩ@15 V** — very VGS-sensitive | ✅ Source-referenced 12 V UVLO → gate never runs far below 15 V. SiC-correct; **fixes the UCC21520 caveat** |
| **Peak current / drive strength** | Peak I_G = ΔV_GS / R_g,total vs driver peak | **±10 A** source/sink; split OUTH/OUTL; R_OH,eff ≈ 0.7 Ω, R_OL ≈ 0.3 Ω | R_g,int = 5 Ω | ✅ 10 A far exceeds needs; pick R_ext for dV/dt; driver never the bottleneck (more headroom than UCC21520) |
| **Average drive power** | P = Q_g·ΔV_GS·f_sw vs driver P_D and bias-supply current | ~965 mW/side; ~985 mW total | Q_g = 55 nC | ✅ 55n·22·100k ≈ **0.12 W/switch**; I_avg ≈ 5.5 mA/ch — trivial |
| **CMTI vs dV/dt** | Switching-node dV/dt vs driver CMTI | **> 150 V/ns** | ~10–30 V/ns expected at 200 V bus | ✅ Even more margin than UCC21520; keep R_g sensible |
| **Timing: dead-time, prop delay, min pulse** | DPT / dead-time plan vs driver timing | t_pd 90 ns; **part-to-part skew 30 ns**; no DT pin (dead-time set in controller / IN+/IN− interlock); 40 ns input deglitch | Dead-time target 100–200 ns | ⚠️ No DT pin → set dead-time in controller; 30 ns skew eats budget (fine for µs DPT pulses) |
| **False turn-on protection** | MOSFET V_GS(th) & Miller vs driver clamp features | **Internal active Miller clamp** (CLMPI, trips 2 V above VEE) + active pulldown | V_GS(th) = **2.0 V min** (low!) | ✅ On-chip clamp removes the false-turn-on worry (**fixes the UCC21520 gap**); negative bias still used |

### What changes vs the UCC21520

- **UVLO now referenced to the source (row 2).** The 12 V UVLO is measured
  VDD−COM, i.e. against the Kelvin source, so it truly guarantees the gate is
  never driven far below 15 V — the region where this onsemi part's R_DS(on)
  climbs (32 mΩ → 41 mΩ). This removes the marginal-UVLO caveat we had with the
  UCC21520.
- **Internal Miller clamp (row 7).** With V_GS(th) as low as 2.0 V, the on-chip
  active clamp (CLMPI, trips 2 V above VEE) adds a low-impedance path against
  dV/dt-induced false turn-on — we no longer rely on negative bias alone.
- **Bonus protection & sensing (not in the table).** DESAT short-circuit
  detection with 400 mA soft turn-off, FLT fault reporting, and an isolated
  AIN→APWM channel that can read a thermal diode / NTC across the barrier — the
  last of which lines up with the Stage-2 junction-temperature (Tj) estimator.
- **Cost: added complexity.** Single-channel → two ICs per leg; DESAT needs a
  blanking network (HV diode, C_blk, series R, clamp) when enabled; 30 ns
  part-to-part skew. On a first board that is more to get right — but DESAT can
  be tied to COM (disabled) for first bring-up and added once the board is
  proven.

### Decision

I will use the **UCC21750**. It responds better to the specific demands of the
onsemi NTH4LN032N065M3S: the source-referenced 12 V UVLO and the internal Miller
clamp directly resolve the two caveats the UCC21520 left open (marginal UVLO
under negative bias, and no clamp against the low 2.0 V threshold). It will make
the design more complicated — a single-channel part means two drivers per leg,
and the DESAT and sensing features add parts and layout work — but for a board
whose purpose is to demonstrate traction-inverter readiness, that is a good
trade-off. The extra protection and the isolated Tj sensing also line up with the
Stage-2 junction-temperature estimator.

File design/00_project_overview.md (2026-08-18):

# SiC Half-Bridge Double Pulse Test — Project Overview

*The plain-language introduction to the design study. Read this before the detailed constraint blocks. It explains what is being built, why, how it works, and which decisions can be varied to observe their effect.*

---

## 1. What am I building?

One switching cell.

Two transistors stacked between the plus and minus of a DC supply, with the middle point between them going out to a load. That two-transistor stack is called a **half-bridge leg**, and it is the single most important building block in power electronics. A complete EV traction inverter is simply **three of these legs side by side** — one per motor phase. Build and fully understand one leg, and the three-phase inverter is just that leg repeated.

So this project is not a "smaller inverter." It is *the fundamental unit the inverter is made of*, built as a laboratory instrument so its behaviour can be measured precisely.

## 2. Why build it — what am I trying to learn?

When a transistor switches a real load on and off, the interesting and destructive physics happens in roughly **20 nanoseconds** — the transition itself, not the steady on-state or off-state. During that transition the device has significant voltage across it **and** significant current through it at the same time, so it dissipates energy, rings, overshoots, and heats. Two things live in that tiny window:

- **Switching loss** — energy burned every time the device turns on or off. In a real inverter this happens tens of thousands of times per second, so it dominates efficiency.
- **The SiC advantage** — silicon-carbide devices switch far faster and with far lower loss than the older silicon IGBTs traction inverters historically used. That advantage *is* the 20 ns transition. Measuring it is the point.

The problem: in a running inverter you cannot cleanly observe those 20 ns — too many things happen at once, continuously. So power electronics uses a controlled laboratory technique to isolate a single switching event.

## 3. How it works — the Double Pulse Test

The technique is the **Double Pulse Test (DPT)**. Instead of running the transistor continuously, you fire it exactly **twice**, in a deliberately arranged circuit, so an oscilloscope can capture one clean switching transition.

The sequence:

- **Pulse 1 (long):** the device under test is switched on. With an inductor as the load, the current ramps up linearly — like slowly filling a tank. When the current reaches the target value (e.g. 10 A), the pulse ends. Pulse 1 exists only to *establish a known current*.
- **The gap (device off):** the current cannot stop instantly — an inductor forces it to keep flowing. It "freewheels" through the other transistor's built-in diode, staying at roughly 10 A. This is the moment the oscilloscope captures the **turn-off** event.
- **Pulse 2 (short):** the device is switched on again, now against a known 10 A already flowing. This captures the **turn-on** event, including how the freewheeling diode recovers.

Two pulses, and you have both the turn-on and turn-off transitions, at a known voltage and known current, frozen on the scope. From those waveforms come the switching-energy numbers (E_on, E_off), the voltage overshoot, the switching speed (dV/dt), and the diode's recovery behaviour.

**The one sentence to remember: everything in this project exists to catch a single switching event on the oscilloscope, cleanly and safely. That measurement is the whole deliverable.**

## 4. What each part is for

Every component and every number is either *setting the conditions of the measurement* or *making the measurement possible and safe*. Grouped by role:

**Setting up the shot — the conditions you switch under:**

- **Bus voltage** — how hard you push the device. Higher voltage gives more realistic, more dramatic data, but more stress on everything and a more dangerous failure (fault energy grows with the square of voltage).
- **Test current** — how much current you interrupt. More current means a bigger, clearer signal to measure, but more stored energy and a bigger event if something fails.

**Making the shot possible — the supporting cast:**

- **Load inductor** — the trick that forces a known current to flow at the instant of switching. It behaves as a "current source you build out of time": hold the device on for a set duration, and the current reaches a set value.
- **DC-link capacitor** — a local energy reservoir sitting right next to the transistors, so the bus voltage does not sag during the fast pulse. Without it, "200 V" would not actually be 200 V at the moment that matters.

**Taking the shot — the actors:**

- **Gate driver** — the circuit that physically flips the transistor on and off, fast and cleanly. A transistor gate needs a surprisingly large, brief burst of current to switch quickly; the driver delivers it, and shapes how fast the switching happens.
- **SiC MOSFET** — the **subject of the entire experiment**. This is the device being characterized. Everything else is scaffolding built around it to get the cleanest, safest picture of it switching.

## 5. What to vary — and what each variation reveals

This is where the project becomes a *study* rather than a single measurement. Once the board works, the value comes from sweeping variables and watching the switching event change. The main axes:

**Bus voltage (e.g. 100 V → 200 V → 400 V).**
Switching losses scale with voltage. Sweeping the bus produces a *curve* of E_on and E_off versus voltage — the single most useful result for predicting behaviour at the real automotive operating point. It also shows the voltage overshoot growing, which is the safety limit that governs how high you can go.

**Test current (e.g. 5 A → 10 A → 20 A).**
Switching losses also scale with current. Sweeping current gives E_on and E_off versus load — together with the voltage sweep, this fully maps the device's switching-loss surface. It also shows how the diode recovery worsens with current.

**Gate resistance (R_g).**
This is the knob that controls switching *speed*. A small gate resistor switches fast — low loss, but violent overshoot and ringing and more electromagnetic noise. A large resistor switches gently — clean and quiet, but higher loss. Sweeping R_g reveals the fundamental **loss-versus-overshoot trade-off**, and produces one of the most instructive graphs in the whole project: there is no free lunch, only a chosen operating point on this curve.

**The device itself (comparing MOSFET candidates).**
Swapping the transistor under test — different R_ds(on), different internal capacitances, different gate charge — shows directly how device choice changes conduction loss, switching loss, and overshoot. This is the comparison that ultimately justifies picking one device for a real design, backed by *your own measurements* rather than datasheet claims.

**Dead time (the gap between the two transistors being on).**
Too short risks both transistors conducting at once (a destructive short across the bus); too long wastes efficiency and distorts the output. Varying it shows the safe operating window.

**Secondary factors worth observing rather than sweeping:**

- **Load inductor construction** (air-core vs ferrite) — affects how clean the switch-node waveform is, because the inductor's own parasitics ring against the circuit.
- **Decoupling capacitor placement** — how physically close the small high-speed capacitors sit to the transistors sets the loop inductance, which directly sets the overshoot.

## 6. The through-line

Strip away the equations and the project is one loop:

*Build the fundamental switching cell of an inverter → use the double pulse test to freeze one switching event → measure the loss, speed, and overshoot in that event → then vary voltage, current, gate speed, and device, and watch how the event changes.*

Every parameter discussed in the detailed constraint blocks is either a condition of that measurement or a variable to sweep in it. Keeping that in view is what turns a page of numbers back into a single, understandable experiment.

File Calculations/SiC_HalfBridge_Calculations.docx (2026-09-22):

SiC Half-Bridge Inverter Leg — Design Calculations

How each governing equation sizes the leg, from first principles to component values

Companion to the Stage-0 design study · Double-Pulse-Test characterization

This document collects every calculation used to model and size the SiC half-bridge leg, and shows how each one feeds the design. The method is deliberate and repeatable: each value is fixed by one governing physical relation and one practical bound. Read that way, none of the numbers are arbitrary — each is the output of a single equation constrained by a single engineering limit, so the same procedure sizes the next design without reference to worked examples.

# 1. Inputs: operating point and device data

Every calculation below draws on two fixed sets of numbers: the operating point the leg is designed around, and the measured device parameters from the component datasheets.

Quantity | Value
DC bus (validation / design target) | 200 V (800 V-ready)
Test current, I_load | 10 A
Switching frequency | 50 – 100 kHz
Positive gate rail | +18 V
Negative gate rail (turn-off bias) | −4 V
Target current-ramp time, Δt | ≈ 25 µs

Parameter | Symbol | Value | Source
On-resistance | R_ds(on) | 32 mΩ | onsemi NTH4LN032N065M3S
Input capacitance | C_iss | 1410 pF | onsemi datasheet
Gate–drain (Miller) charge | Q_GD | 14 nC | onsemi (at 400 V)
Total gate charge | Q_G | 55 nC | onsemi (−3/18 V)
Internal gate resistance | R_G | 5.0 Ω | onsemi datasheet
Driver peak source / sink | ±I_pk | ±10 A | TI UCC21750
Driver pull-up resistance | R_OH | ≈ 0.7 Ω | TI UCC21750

# 2. Load inductor

The load inductor acts as a controllable current ramp: with the full bus voltage across it, current rises linearly. Its value is therefore not chosen directly — a comfortable ramp time is selected first, and the inductance follows from the inductor law.

di/dt = V / L → L = V · Δt / ΔI

A ramp time of a few tens of microseconds is the sweet spot: long enough to set precisely on a function generator and resolve on an oscilloscope, short enough to avoid heating and to keep the DC-link charge demand modest. Choosing Δt = 25 µs to reach 10 A at 200 V gives:

L = 200 V × 25 µs / 10 A = 500 µH

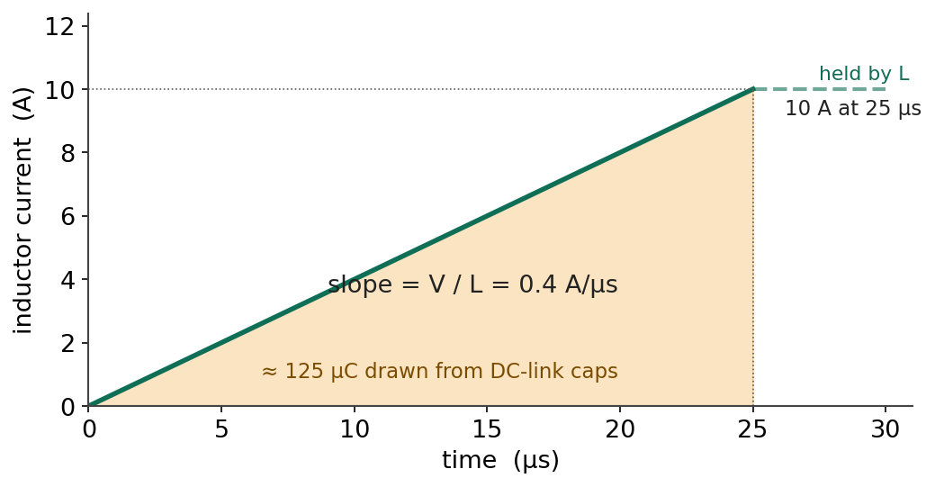
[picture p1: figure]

Figure 1 — Inductor current during the on-pulse. The slope is set by V/L; the shaded area is the charge the DC-link must supply.

This yields di/dt = 0.4 A/µs. Two bounds accompany the value: the inductor must not saturate below the test current (rated saturation current with margin above 10 A), and the load inductance must not be confused with the commutation-loop inductance, which is the term that drives turn-off overshoot.

# 3. DC-link bulk capacitor

During the ramp, current is drawn from the capacitors, not from the distant supply (too slow through its wiring inductance to react over microseconds). The charge delivered is the area under the current ramp of Figure 1:

Q = ½ · I · t = ½ × 10 A × 25 µs = 125 µC

The bus is allowed to sag by a chosen tolerance — here ≤ 1 % of 200 V ≈ 2 V — which sets the minimum capacitance:

C ≥ Q / ΔV = 125 µC / 2 V ≈ 63 µF → round up to ≈ 100 µF

At 100 µF the sag is only ≈ 1.25 V (a conservative worst case, since the supply recharges slightly during the pulse). Two further bounds fix the part: voltage rating uses a 2× derating of the working bus, so 200 V → ≥ 400 V (500–630 V film chosen); and the dielectric is film (polypropylene), not electrolytic, because DC-link duty needs low ESR/ESL and high ripple-current capability.

## 3.1 Realising 100 µF as a parallel bank

A single 100 µF / 630 V film capacitor is physically large and costly, so the bulk is built as a parallel bank of smaller film parts. Capacitances in parallel add, so:

5 × 22 µF = 110 µF ≈ target

Paralleling also lowers the effective ESR and ESL and lets the caps be distributed along the bus, close to the switches — an electrical improvement, not merely a sourcing workaround.

# 4. Gate drive rails

The gate is driven between a positive on-rail and a small negative off-rail. The positive value is set by the MOSFET (+18 V for this onsemi part); the negative value (−4 V) holds the switch firmly off and suppresses Miller-induced false turn-on. The drive swing that appears in the gate-current calculations is the difference between them:

V_drive = V_on − V_off = +18 − (−4) = 22 V

# 5. Gate resistor and peak gate current

The external gate resistor is bounded by a single relation and a single constraint — the driver's peak current rating:

I_peak = V_drive / R_g,total (limit: I_peak ≤ ±10 A)

The total loop resistance is a sum of three series terms, only one of which the designer chooses:

R_g,total = R_driver (≈0.7 Ω) + R_g,ext + R_g,int (5.0 Ω)

The minimum permissible total resistance is:

R_g,total(min) = 22 V / 10 A = 2.2 Ω

But the fixed internal terms already sum to ≈ 5.7 Ω — above the 2.2 Ω floor — so even with R_g,ext = 0 the peak current is only ≈ 22 / 5.7 ≈ 4 A. The current limit is therefore never binding: external R_g stops being a limit-driven choice and becomes purely the switching-speed knob. At the chosen R_g,ext = 5 Ω, R_g,total ≈ 10.7 Ω and I_peak ≈ 22 / 10.7 ≈ 2.1 A — comfortably safe on both edges.

# 6. Switching dynamics (the Miller plateau)

The switching event does not occur while the gate charges up; it occurs during the flat region of the gate-charge curve — the Miller plateau — where the drain voltage swings while V_GS is held constant and the driver moves the Miller charge Q_GD.

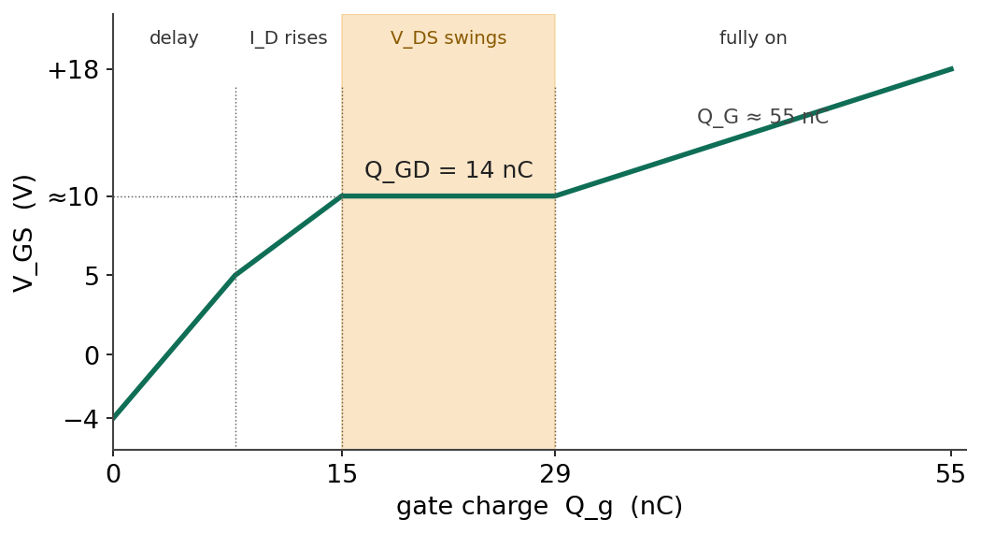
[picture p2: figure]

Figure 2 — Gate-source voltage vs gate charge. Switching happens in the shaded plateau, where V_DS swings and the driver moves Q_GD.

During the plateau the gate sits at the plateau voltage (≈ 10 V, read from the gate-charge curve) while the driver rail is at +18 V, so the available current and the resulting plateau duration are:

I_g,plateau = (18 − 10) / R_g,total = 8 / 10.7 ≈ 0.75 A

t_plateau = Q_GD / I_g,plateau = 14 nC / 0.75 A ≈ 19 ns

This ≈ 19 ns is the real V_DS transition time — the honest counterpart of a naïve RC estimate (τ = R_g,total × C_iss ≈ 10.7 Ω × 1410 pF ≈ 15 ns), which ignores that the switching happens at constant V_GS rather than while the gate charges through C_iss.

## 6.1 R_g as the design lever

Rearranging shows the switching time is directly proportional to the gate resistance:

t_plateau = Q_GD · R_g,total / (V_rail − V_plateau) ∝ R_g,total

Because the turn-on energy scales as E_on ≈ ½ · V_bus · I_load · t_transition, doubling the plateau time roughly doubles the turn-on loss. The trade-off is monotonic and is exactly what the double-pulse test sweeps:

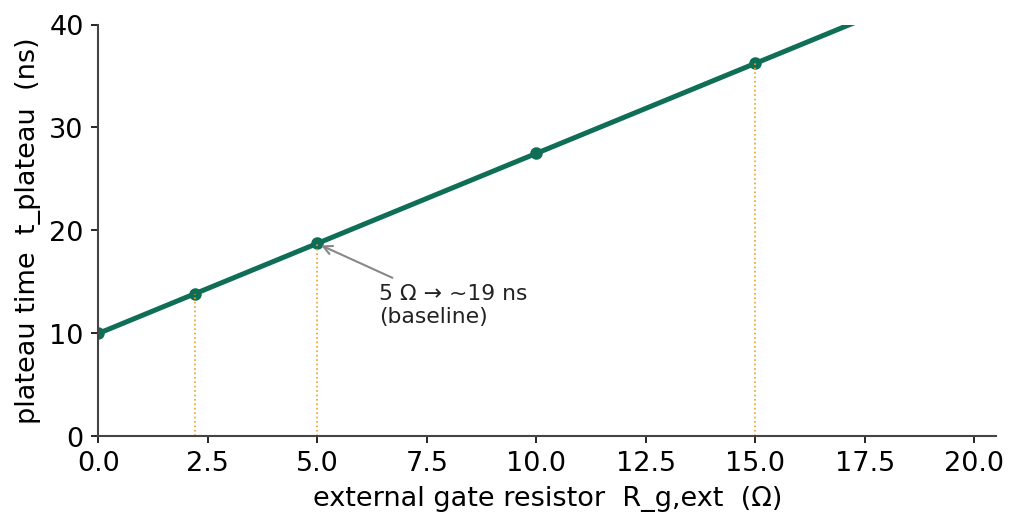
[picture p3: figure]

Figure 3 — Switching (plateau) time versus external gate resistor. Larger R_g → slower switching, higher loss, tamer overshoot.

R_g,ext | R_g,total | t_plateau (approx.)
2.2 Ω | ≈ 7.9 Ω | ≈ 14 ns (faster · lower loss · more overshoot)
5 Ω | ≈ 10.7 Ω | ≈ 19 ns (baseline / centre of sweep)
10 Ω | ≈ 15.7 Ω | ≈ 28 ns
15 Ω | ≈ 20.7 Ω | ≈ 37 ns (slower · higher loss · tamer overshoot)

The formula predicts the trend; the exact E_on/E_off and overshoot at each value are obtained by measurement, because at these edge speeds the outcome is dominated by real layout parasitics the equation does not capture. R_g,ext is therefore left provisional at 5 Ω (centre of the sweep) on a swappable footprint.

# 7. Driver decoupling capacitors

The decoupling capacitors on the driver do not see the 200 V bus — they see only the local supply at their node — so the 2× derating is applied to that voltage, not the bus:

- VDD/VEE decoupling (≈ +18 V node): 18 × 2 = 36 V → 35 V-class ceramic (MLCC).
- VCC decoupling (3.3–5 V logic): a ≥ 25 V ceramic is ample.

These are ceramic MLCCs, not film, because the job is a fast local current burst (low ESL), not bulk energy storage. One correction the calculation must include is the MLCC DC-bias effect: a class-2 (X5R/X7R) capacitor loses capacitance under applied voltage, so a 22 µF/35 V part may deliver only ≈ 10–14 µF at 18 V. The datasheet requires > 10 µF, so the value is chosen with margin (22 µF, or two 15 µF in parallel) to stay above 10 µF after the derating.

# 8. Bringing it together — the leg model

The calculations interlock into a single, self-consistent model of the leg. The load inductor (500 µH) sets the current slope (0.4 A/µs), which fixes the pulse width (25 µs) needed to reach the 10 A test current. That pulse width, with the test current, sets the charge the DC-link must supply (125 µC), which — under a 1 % sag budget — sizes the bulk capacitance (100 µF). Independently, the gate rails (+18/−4 V) fix the drive swing (22 V), which with the driver's 10 A limit sets the minimum gate resistance (2.2 Ω); the chosen 5 Ω, combined with the device's Miller charge (14 nC), sets the switching time (≈ 19 ns) and hence the turn-on energy the whole experiment exists to measure. Every arrow in that chain is one equation and one bound.

The table below collects the computed quantities in one place.

Quantity | Governing relation | Result
Load inductor | L = V·Δt / ΔI | 500 µH
Current slope | di/dt = V / L | 0.4 A/µs
Charge per pulse | Q = ½·I·t | 125 µC
DC-link bulk cap | C ≥ Q / ΔV | ≈ 100 µF
Gate drive swing | V_drive = V_on − V_off | 22 V
Min. gate resistance | R_g,total ≥ V_drive / I_pk | 2.2 Ω
Peak gate current (R_g,ext=5 Ω) | I_pk = V_drive / R_g,total | ≈ 2.1 A
Plateau (switching) time | t = Q_GD / I_g,plateau | ≈ 19 ns

## 8.1 Realised component choices

Role | Chosen part / value | Rating
Switches (DUT + high-side) | onsemi NTH4LN032N065M3S | 650 V / 32 mΩ SiC
Gate drivers (×2) | TI UCC21750 | isolated, ±10 A
DC-link bulk | 5 × 22 µF film (TDK B32776) | 630 V, ≈110 µF
DC-link / decoupling voltage | 2× derating of local node | see §4, §8
Driver decoupling (VDD/VEE) | 2 × 15 µF MLCC | 35 V
External gate resistors | R_g(on) / R_g(off), socketed | ≈ 5 Ω start
Load inductor | toroid 500 µH / 15 A (or air coil) | ≥ 15 A

# 9. Appendix — air-core load inductor (alternative)

If a suitable cored 500 µH / ≥15 A inductor is unavailable, the load can be a hand-wound single-layer air-core coil, which cannot saturate (no core), keeping di/dt perfectly linear at any current. Its inductance is set purely by geometry, via Wheeler's approximation:

L (µH) ≈ d² · N² / (18d + 40ℓ) [d, ℓ in inches]

with d the coil diameter, ℓ the winding length and N the number of turns. The value grows with N² and with diameter, and falls as the coil is stretched. In practice the coil is wound on a rigid non-magnetic form (≈ 30–50 mm diameter) with insulated wire sized for 10 A (≈ 1.5–2.5 mm²), then its inductance is measured with an LCR meter and turns are added or removed until it reads ≈ 500 µH — verification rather than trust, since the formula is accurate only to ≈ ±15 %.

Design calculations — values provisional pending measurement (simulation and/or double-pulse test).

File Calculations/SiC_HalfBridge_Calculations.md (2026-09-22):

**SiC Half-Bridge Inverter Leg — Design Calculations**

How each governing equation sizes the leg, from first principles to component values

_Companion to the Stage-0 design study · Double-Pulse-Test characterization_

This document collects every calculation used to model and size the SiC half-bridge leg, and shows how each one feeds the design. The method is deliberate and repeatable: **each value is fixed by one governing physical relation and one practical bound.** Read that way, none of the numbers are arbitrary — each is the output of a single equation constrained by a single engineering limit, so the same procedure sizes the next design without reference to worked examples.

# **1\. Inputs: operating point and device data**

Every calculation below draws on two fixed sets of numbers: the operating point the leg is designed around, and the measured device parameters from the component datasheets.

| **Quantity** | **Value** |
| --- | --- |
| **DC bus (validation / design target)** | 200 V (800 V-ready) |
| **Test current, I_load** | 10 A |
| **Switching frequency** | 50 – 100 kHz |
| **Positive gate rail** | +18 V |
| **Negative gate rail (turn-off bias)**  | −4 V |
| **Target current-ramp time, Δt** | ≈ 25 µs |

| **Parameter** | **Symbol** | **Value** | **Source** |
| --- | --- | --- | --- |
| **On-resistance** | R_ds(on) | 32 mΩ | onsemi NTH4LN032N065M3S |
| **Input capacitance** | C_iss | 1410 pF | onsemi datasheet |
| **Gate–drain (Miller) charge** | Q_GD | 14 nC | onsemi (at 400 V) |
| **Total gate charge** | Q_G | 55 nC | onsemi (−3/18 V) |
| **Internal gate resistance** | R_G | 5.0 Ω | onsemi datasheet |
| **Driver peak source / sink**  | ±I_pk | ±10 A | TI UCC21750 |
| **Driver pull-up resistance**  | R_OH | ≈ 0.7 Ω | TI UCC21750 |

# **2\. Load inductor**

The load inductor acts as a controllable current ramp: with the full bus voltage across it, current rises linearly. Its value is therefore not chosen directly — a comfortable ramp time is selected first, and the inductance follows from the inductor law.

_di/dt = V / L → L = V · Δt / ΔI_

A ramp time of a few tens of microseconds is the sweet spot: long enough to set precisely on a function generator and resolve on an oscilloscope, short enough to avoid heating and to keep the DC-link charge demand modest. Choosing Δt = 25 µs to reach 10 A at 200 V gives:

_L = 200 V × 25 µs / 10 A = 500 µH_

![]()

_Figure 1 — Inductor current during the on-pulse. The slope is set by V/L; the shaded area is the charge the DC-link must supply._

This yields di/dt = 0.4 A/µs. Two bounds accompany the value: the inductor must not _saturate_ below the test current (rated saturation current with margin above 10 A), and the load inductance must not be confused with the commutation-loop inductance, which is the term that drives turn-off overshoot.

# **3\. DC-link bulk capacitor**

During the ramp, current is drawn from the capacitors, not from the distant supply (too slow through its wiring inductance to react over microseconds). The charge delivered is the area under the current ramp of Figure 1:

_Q = ½ · I · t = ½ × 10 A × 25 µs = 125 µC_

The bus is allowed to sag by a chosen tolerance — here ≤ 1 % of 200 V ≈ 2 V — which sets the minimum capacitance:

_C ≥ Q / ΔV = 125 µC / 2 V ≈ 63 µF → round up to ≈ 100 µF_

At 100 µF the sag is only ≈ 1.25 V (a conservative worst case, since the supply recharges slightly during the pulse). Two further bounds fix the part: voltage rating uses a 2× derating of the working bus, so 200 V → ≥ 400 V (500–630 V film chosen); and the dielectric is film (polypropylene), not electrolytic, because DC-link duty needs low ESR/ESL and high ripple-current capability.

## **3.1 Realising 100 µF as a parallel bank**

A single 100 µF / 630 V film capacitor is physically large and costly, so the bulk is built as a parallel bank of smaller film parts. Capacitances in parallel _add_, so:

_5 × 22 µF = 110 µF ≈ target_

Paralleling also lowers the effective ESR and ESL and lets the caps be distributed along the bus, close to the switches — an electrical improvement, not merely a sourcing workaround.

# **4\. Gate drive rails**

The gate is driven between a positive on-rail and a small negative off-rail. The positive value is set by the MOSFET (+18 V for this onsemi part); the negative value (−4 V) holds the switch firmly off and suppresses Miller-induced false turn-on. The drive swing that appears in the gate-current calculations is the difference between them:

_V_drive = V_on − V_off = +18 − (−4) = 22 V_

# **5\. Gate resistor and peak gate current**

The external gate resistor is bounded by a single relation and a single constraint — the driver's peak current rating:

_I_peak = V_drive / R_g,total (limit: I_peak ≤ ±10 A)_

The total loop resistance is a sum of three series terms, only one of which the designer chooses:

_R_g,total = R_driver (≈0.7 Ω) + R_g,ext + R_g,int (5.0 Ω)_

The minimum permissible total resistance is:

_R_g,total(min) = 22 V / 10 A = 2.2 Ω_

But the fixed internal terms already sum to ≈ 5.7 Ω — above the 2.2 Ω floor — so even with R_g,ext = 0 the peak current is only ≈ 22 / 5.7 ≈ 4 A. The current limit is therefore **never binding**: external R_g stops being a limit-driven choice and becomes purely the switching-speed knob. At the chosen R_g,ext = 5 Ω, R_g,total ≈ 10.7 Ω and I_peak ≈ 22 / 10.7 ≈ 2.1 A — comfortably safe on both edges.

# **6\. Switching dynamics (the Miller plateau)**

The switching event does not occur while the gate charges up; it occurs during the flat region of the gate-charge curve — the Miller plateau — where the drain voltage swings while V_GS is held constant and the driver moves the Miller charge Q_GD.

![]()

_Figure 2 — Gate-source voltage vs gate charge. Switching happens in the shaded plateau, where V_DS swings and the driver moves Q_GD._

During the plateau the gate sits at the plateau voltage (≈ 10 V, read from the gate-charge curve) while the driver rail is at +18 V, so the available current and the resulting plateau duration are:

_I_g,plateau = (18 − 10) / R_g,total = 8 / 10.7 ≈ 0.75 A_

_t_plateau = Q_GD / I_g,plateau = 14 nC / 0.75 A ≈ 19 ns_

This ≈ 19 ns is the real V_DS transition time — the honest counterpart of a naïve RC estimate (τ = R_g,total × C_iss ≈ 10.7 Ω × 1410 pF ≈ 15 ns), which ignores that the switching happens at constant V_GS rather than while the gate charges through C_iss.

## **6.1 R_g as the design lever**

Rearranging shows the switching time is directly proportional to the gate resistance:

_t_plateau = Q_GD · R_g,total / (V_rail − V_plateau) ∝ R_g,total_

Because the turn-on energy scales as E_on ≈ ½ · V_bus · I_load · t_transition, doubling the plateau time roughly doubles the turn-on loss. The trade-off is monotonic and is exactly what the double-pulse test sweeps:

![]()

_Figure 3 — Switching (plateau) time versus external gate resistor. Larger R_g → slower switching, higher loss, tamer overshoot._

| **R_g,ext** | **R_g,total** | **t_plateau (approx.)** |
| --- | --- | --- |
| **2.2 Ω** | ≈ 7.9 Ω | ≈ 14 ns (faster · lower loss · more overshoot) |
| **5 Ω** | ≈ 10.7 Ω | ≈ 19 ns (baseline / centre of sweep) |
| **10 Ω** | ≈ 15.7 Ω | ≈ 28 ns |
| **15 Ω** | ≈ 20.7 Ω | ≈ 37 ns (slower · higher loss · tamer overshoot) |

The formula predicts the trend; the exact E_on/E_off and overshoot at each value are obtained by **measurement**, because at these edge speeds the outcome is dominated by real layout parasitics the equation does not capture. R_g,ext is therefore left provisional at 5 Ω (centre of the sweep) on a swappable footprint.

# **7\. Driver decoupling capacitors**

The decoupling capacitors on the driver do not see the 200 V bus — they see only the local supply at their node — so the 2× derating is applied to _that_ voltage, not the bus:

- VDD/VEE decoupling (≈ +18 V node): 18 × 2 = 36 V → 35 V-class ceramic (MLCC).
- VCC decoupling (3.3–5 V logic): a ≥ 25 V ceramic is ample.

These are ceramic MLCCs, not film, because the job is a fast local current burst (low ESL), not bulk energy storage. One correction the calculation must include is the MLCC _DC-bias effect_: a class-2 (X5R/X7R) capacitor loses capacitance under applied voltage, so a 22 µF/35 V part may deliver only ≈ 10–14 µF at 18 V. The datasheet requires > 10 µF, so the value is chosen with margin (22 µF, or two 15 µF in parallel) to stay above 10 µF after the derating.

# **8\. Bringing it together — the leg model**

The calculations interlock into a single, self-consistent model of the leg. The load inductor (500 µH) sets the current slope (0.4 A/µs), which fixes the pulse width (25 µs) needed to reach the 10 A test current. That pulse width, with the test current, sets the charge the DC-link must supply (125 µC), which — under a 1 % sag budget — sizes the bulk capacitance (100 µF). Independently, the gate rails (+18/−4 V) fix the drive swing (22 V), which with the driver's 10 A limit sets the minimum gate resistance (2.2 Ω); the chosen 5 Ω, combined with the device's Miller charge (14 nC), sets the switching time (≈ 19 ns) and hence the turn-on energy the whole experiment exists to measure. Every arrow in that chain is one equation and one bound.

The table below collects the computed quantities in one place.

| **Quantity** | **Governing relation** | **Result** |
| --- | --- | --- |
| **Load inductor** | L = V·Δt / ΔI | 500 µH |
| **Current slope** | di/dt = V / L | 0.4 A/µs |
| **Charge per pulse** | Q = ½·I·t | 125 µC |
| **DC-link bulk cap** | C ≥ Q / ΔV | ≈ 100 µF |
| **Gate drive swing** | V_drive = V_on − V_off | 22 V |
| **Min. gate resistance** | R_g,total ≥ V_drive / I_pk | 2.2 Ω |
| **Peak gate current (R_g,ext=5 Ω)** | I_pk = V_drive / R_g,total | ≈ 2.1 A |
| **Plateau (switching) time** | t = Q_GD / I_g,plateau | ≈ 19 ns |

## **8.1 Realised component choices**

| **Role** | **Chosen part / value** | **Rating** |
| --- | --- | --- |
| **Switches (DUT + high-side)** | onsemi NTH4LN032N065M3S | 650 V / 32 mΩ SiC |
| **Gate drivers (×2)** | TI UCC21750 | isolated, ±10 A |
| **DC-link bulk** | 5 × 22 µF film (TDK B32776) | 630 V, ≈110 µF |
| **DC-link / decoupling voltage** | 2× derating of local node | see §4, §8 |
| **Driver decoupling (VDD/VEE)**  | 2 × 15 µF MLCC | 35 V |
| **External gate resistors** | R_g(on) / R_g(off), socketed | ≈ 5 Ω start |
| **Load inductor** | toroid 500 µH / 15 A (or air coil) | ≥ 15 A |

# **9\. Appendix — air-core load inductor (alternative)**

If a suitable cored 500 µH / ≥15 A inductor is unavailable, the load can be a hand-wound single-layer air-core coil, which _cannot saturate_ (no core), keeping di/dt perfectly linear at any current. Its inductance is set purely by geometry, via Wheeler's approximation:

_L (µH) ≈ d² · N² / (18d + 40ℓ) \[d, ℓ in inches\]_

with d the coil diameter, ℓ the winding length and N the number of turns. The value grows with N² and with diameter, and falls as the coil is stretched. In practice the coil is wound on a rigid non-magnetic form (≈ 30–50 mm diameter) with insulated wire sized for 10 A (≈ 1.5–2.5 mm²), then its inductance is measured with an LCR meter and turns are added or removed until it reads ≈ 500 µH — verification rather than trust, since the formula is accurate only to ≈ ±15 %.

_Design calculations — values provisional pending measurement (simulation and/or double-pulse test)._

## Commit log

2026-06-26 Initial commit: project structure and Stage 0 design study
2026-10-22 KiCad rev B : schéma complet et PCB 4 couches de la carte DPT
    Schéma :
    - bus refermé (net DC-), C2 en HF entre VDC et DC-, bobine J3 entre SW et VDC
    - alimentations de grille isolées séparées (MGJ2D121805BSC x2, +18/-5 V) avec précharges
    - régulateur 3,3 V, interface STM32 (J7), protection DESAT, boucle Rogowski J5
    - LED de défaut remises dans le bon sens, références corrigées (Q1, Q2, J3, C11-C15)
    PCB 4 couches (F.Cu / In1 DC- et GND / In2 VDC / B.Cu) : placement et routage.
    Ajout d'un .gitignore pour les caches et sauvegardes KiCad.
    Détail des changements du schéma : schematic/CHANGEMENTS.md
    Claude-Session: https://cl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
